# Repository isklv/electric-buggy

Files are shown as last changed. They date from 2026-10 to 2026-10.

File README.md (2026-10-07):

# ⚡ Electric Utility Buggy 2-Seater (RWD, IRS)
> Двухместный утилитарный электробагги с независимой подвеской (IRS), модульной АКБ 72V (50+ км), зимним снегоотвалом и каркасом из профильной трубы **без применения трубогиба**.





---

## 📌 Основные характеристики

| Параметр | Значение | Примечания |
| :--- | :--- | :--- |
| **Пассажировместимость** | 2 человека (Side-by-Side) | Анатомические сиденья, ширина кабины 1100 мм |
| **Привод** | Задний (RWD), двойные поперечные рычаги на 4 колесах | Кулаки 2108 + адаптер АД-01, приводы ВАЗ-2108 |
| **Максимальная скорость** | 55 км/ч (4-я) / 66 км/ч (5-я) | КПП 2108 как редуктор; 2-я — пониженная для отвала (27 км/ч) |
| **Пиковая сила тяги** | ~330 кгс на 2-й передаче | Вход КПП ограничен 135 Нм током контроллера |
| **Батарея №1 (Базовая)** | 72V (20S) 48 Ah (~3.5 кВт·ч брутто) | Запас хода: **46 км летом / 35 км зимой** |
| **Батарея №2 (Модуль расширения)**| + 72V 48 Ah (параллельное подключение) | Суммарно: **92 км летом / 70 км зимой** |
| **Электромотор** | QS Motor 138 70H V3 | Ном. 3 кВт, пик 11–13 кВт, редуктор 1:2.35 |
| **Трансмиссия** | Цепь 520 15Т/15Т → КПП ВАЗ-2108 → приводы 2108 | Общее передаточное: 1:8.71 (4-я), 1:18.1 (2-я) |
| **Клиренс / Колея / База** | 280 мм / 1300 мм / 2050 мм | Колеса 175/70 R13 (разболтовка 4х98) |
| **Технология рамы** | Профильная труба (без трубогиба) | Профиль 50х50х2.5, 40х40х2.0, 40х20х2.0, лист 3 мм |
| **Зимний отвал** | Ширина 1400 мм, поворотный ($\pm 25^\circ$) | Пружинный механизм откидывания, быстросъем 50х50 |

---

## 📂 Структура проекта

* **`electric_buggy.FCStd`** — Полный параметрический 3D-проект для **FreeCAD** с деревом объектов и чертежным листом *TechDraw_Blueprint*.
* **`electric_buggy.blend`** — Полноценная 3D-сцена для **Blender 5.x** со всеми узлами, PBR-материалами, коллекциями, освещением и камерой.
* **`viewer.html`** — Детальная интерактивная 3D-модель (Three.js): слои, фары с ночным режимом, готовые ракурсы, названия узлов при наведении, экспорт GLB. Открывается прямо в браузере. Онлайн: https://isklv.github.io/electric-buggy/
* **`web/buggy_scene.js`** — Описание детальной 3D-сцены (общее для браузера и экспорта OBJ).
* **`generate_3d.py`** — Сборка `viewer.html` и `buggy_frame_chassis.obj/.mtl` из `chassis_geometry.py`. OBJ (~35 МБ) не хранится в git: он собирается при публикации на GitHub Pages или локально (`cd tools && npm install`, затем `python3 generate_3d.py`).
* **`FABRICATION_AND_ELECTRICAL_GUIDE.md`** — Практическое руководство по сварке рамы, сборке стапеля, электрической схеме 72V/12V, предзаряду (Precharge) и настройке BMS.
* **`calculations.py`** — Инженерный скрипт расчета тяги, скоростей, токов и спецификации проката.
* **`drawings/`** — Комплект подробных рабочих чертежей в векторном формате SVG:
  * `01_frame_assembly.svg` — Общий сборочный чертеж рамы (габариты, проекции, углы резов).
  * `02_front_suspension_arms.svg` — Деталировка передних А-образных рычагов под сайлентблоки и шаровые ВАЗ-2108.
  * `03_rear_irs_arms.svg` — Задняя независимая подвеска IRS со схемой регулировки схождения на рулевом сгоне ВАЗ.
  * `04_powertrain_motor_plate.svg` — Моторная плита QS138 с пазами натяжки цепи и опорами дифференциала UCP206.
  * `05_snow_plow_assembly.svg` — Поворотный отвал 1400 мм с пружинной защитой от ударов и быстросъемом.
  * `06_battery_box_thermal.svg` — Съемный термобокс АКБ 72V с утеплителем ЭППС и подогревом 12V.
  * `07_suspension_corner_assembly.svg` — Угол подвески в сборе (единый на 4 колеса), координаты шарниров.
  * `08_knuckle_adapter_AD01.svg` — Адаптер АД-01 на кулак 2108: верхний ШС + рулевой рычаг.
  * `09_front_subframe_kinematics.svg` — Передний подрамник, графики развала и подруливания.
  * `10_steering_system.svg` — Рулевая трапеция (Аккерман), требования к рейке, колонка.
  * `11_power_module_gearbox.svg` — Силовой модуль QS138 → цепь → КПП 2108 → приводы (заменяет лист 04).
  * `12_brake_system.svg` — Тормозная гидравлика, педальный узел, стояночный тормоз.
  * `13_brackets_hardware.svg` — Кронштейны, имитатор ШРУС, моменты затяжки, прочность рычагов.
* **`chassis_geometry.py`** — Единый источник геометрии шасси: кинематика подвески, пружины, рулевое, тормоза, трансмиссия.
* **`generate_assembly_drawings.py`** — Генератор листов 07–13 из `chassis_geometry.py`.
* **`CHASSIS_ASSEMBLY_GUIDE.md`** — Сборка подвески, рулевого, тормозов и силового модуля; что замерить на доноре.

---

## 🛠 Ведомость закупки металлопроката (Рама без трубогиба)

Все углы каркаса выполняются торцевыми запилами (65°, 45°, 38°, 52°) и усиливаются треугольными косынками из стали 3 мм.

| Профиль | Сечение / Стенка | Метраж с запасом 10% | Количество хлыстов (по 6 м) | Назначение |
| :--- | :--- | :--- | :--- | :--- |
| **Профтруба 50х50** | 50х50х2.5 мм | 13.0 м | **3 хлыста** (18 м) | Нижний периметр, подрамники, крепеж отвала |
| **Профтруба 40х40** | 40х40х2.0 мм | 18.0 м | **3 хлыста** (18 м) | Клетка безопасности, дуги, диагонали крыши |
| **Профтруба 40х20** | 40х20х2.0 мм | 12.0 м | **2 хлыста** (12 м) | Каркас сидений, тоннель АКБ, стойки амортизаторов |
| **Листовая сталь** | Лист Ст3, t = 3.0 мм | ~1.5 м² | 1 лист | Косынки 80х80 мм в углы, уши сайлентблоков, кронштейны |

---

## ⚡ Принципиальная электрическая схема 72V / 12V

```
 [АКБ №1: 72V 48Ah] ---> [Smart BMS 100A] ---> [DC Автомат 100A] ---\
                                                                     +---> [ШИНА ПЛЮС 72V]
 [АКБ №2: 72V 48Ah] ---> [Smart BMS 100A] ---> [DC Автомат 100A] ---/            |
 (опция расширения)                                                              |
                                                                                 v
                                                                  [Главный контактор 72V 200A]
                                                                  (с резистором Precharge 1k 25W)
                                                                                 |
                                                                                 v
 [МАССА МИНУС 72V] <--------------------------------------------------- [Контроллер VOTOL EM150]
        |                                                                        |
        |---> [DC-DC 72V -> 12V 30A]                                             | (3 фазы U,V,W + Холлы)
        |          |                                                             v
        |          v                                                    [Мотор QS138 70H V3]
        |     [Бортовая сеть 12V]
        |     - Подогрев ячеек АКБ (термореле KSD9700 +5°C...+20°C)
        |     - Лебедка подъема отвала 2000 lbs
        |     - LED фары, стоп-сигналы, звуковой сигнал
```

---

## ❄️ Зимняя эксплуатация и уборка снега

1. **Термобокс с подогревом:** Ячейки NMC утеплены экструдированным пенополистиролом (ЭППС) 20 мм. Внутри установлен греющий мат 12V 40W. При падении температуры ниже +5°C автоматика подогревает ячейки, исключая деградацию лития.
2. **Безопасный отвал 1400 мм:** При наезде на люк, бордюр или вмерзший камень ковш откидывается вперед на нижнем шарнире, растягивая две мощные пружины, перескакивает препятствие и возвращается назад без повреждения рамы.
3. **Подъем отвала:** Осуществляется электрической квадроциклетной лебедкой 12V с управлением тумблером на панели.

---

## 🚀 Быстрый старт

### 1. Открыть 3D-модель в браузере:
Просто откройте файл `viewer.html` в Google Chrome или Firefox:
```bash
google-chrome viewer.html
```

### 2. Открыть в FreeCAD:
```bash
FreeCAD electric_buggy.FCStd
```

### 3. Открыть в Blender:
```bash
blender electric_buggy.blend
```

---

## 📄 Лицензия
Проект распространяется под лицензией **MIT** — открыт для свободного использования, модификации и постройки.

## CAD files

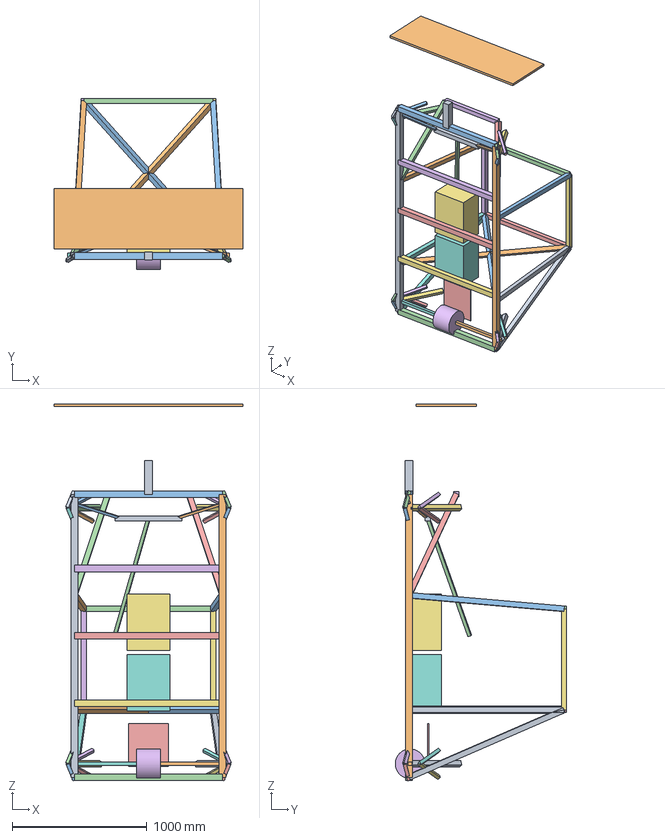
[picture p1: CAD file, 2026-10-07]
electric_buggy.FCStd
1400.0 x 1271.9 x 2797.7 mm
Sill_Left
Sill_Right
Cross_Front
Cross_Rear
Cross_Center
Cross_Susp_F
Cross_Susp_R
B_Pillar_L
B_Pillar_R
A_Pillar_L
A_Pillar_R
Roof_Front
Roof_Rear
Roof_Side_L
Roof_Side_R
Engine_Bay_Diag_L
Engine_Bay_Diag_R
Rear_Cross_Diag1
Rear_Cross_Diag2
Hood_Diag_L
Hood_Diag_R
Hood_Cross
Battery_Pack_1_50km
Battery_Pack_2_Ext50km
Plow_Hitch_Receiver
Snow_Blade_1400mm
Front_Lower_Arm_F_R
Front_Lower_Arm_R_R
Front_Upper_Arm_F_R
Front_Upper_Arm_R_R
Front_Shock_R
Front_Lower_Arm_F_L
Front_Lower_Arm_R_L
Front_Upper_Arm_F_L
Front_Upper_Arm_R_L
Front_Shock_L
Rear_Lower_Arm_F_R
Rear_Lower_Arm_R_R
Rear_Upper_Arm_F_R
Rear_Upper_Arm_R_R
Rear_Shock_R
Rear_CV_Shaft_R
Rear_Lower_Arm_F_L
Rear_Lower_Arm_R_L
Rear_Upper_Arm_F_L
Rear_Upper_Arm_R_L
Rear_Shock_L
Rear_CV_Shaft_L
Steering_Rack_Oka
Steering_TieRod_R
Steering_TieRod_L
Steering_Column
Motor_Mount_Tensioner_Plate
Rear_Differential_VAZ

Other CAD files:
electric_buggy.blend

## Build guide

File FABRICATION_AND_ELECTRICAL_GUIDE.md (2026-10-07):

# Полное практическое руководство: Постройка двухместного электробагги (RWD, IRS)

## 1. Спецификация закупки (Бюджетная смета)

### Металлопрокат
1. **Профильная труба 50х50х2.5 мм** — 3 хлыста по 6 м (18 м). *Назначение:* нижний силовой периметр, лонжероны, балка отвала, крепления редуктора.
2. **Профильная труба 40х40х2.0 мм** — 3 хлыста по 6 м (18 м). *Назначение:* стойки безопасности клетки, брусья крыши, укосины.
3. **Профильная труба 40х20х2.0 мм** — 2 хлыста по 6 м (12 м). *Назначение:* каркас сидений, тоннель аккумулятора, подрамники амортизаторов.
4. **Листовая сталь 3.0 мм** — 1.5 м² (нарезка на плазморезе/болгаркой: косынки жесткости 80х80 мм, кронштейны ушей сайлентблоков и амортизаторов).

### Доноры ВАЗ-2108 / Ока (Авторазборка / Новые)
1. **Ступичные узлы и кулаки ВАЗ-2108 в сборе с тормозными дисками и суппортами** — 4 шт (унификация по кругу).
2. **Передние приводы ВАЗ-2108 со ШРУСами (гранатами)** — 2 шт (для задней независимой подвески).
3. **Рулевая рейка «Ока» (1111)** с рулевыми тягами и наконечниками — 1 шт.
4. **Сайлентблоки ВАЗ-2108** (нижнего рычага / ромашки) — 16 шт (по 2 на каждый А-образный рычаг).
5. **Шаровые опоры ВАЗ-2108** — 8 шт (верх/низ на перед и зад).
6. **Главный тормозной цилиндр ВАЗ-2108** с бачком и педальным узлом — 1 комплект.
7. **Колеса:** Диски R13 (разболтовка 4х98) + зимняя шипованная резина 175/70 R13.

### Электрокомпоненты силовой части (72V)
1. **Электромотор:** QS Motor 138 70H V3 (3 кВт ном, 11-13 кВт пик, со встроенным шестеренчатым редуктором 1:2.35).
2. **Контроллер:** VOTOL EM150-2SP или FarDriver ND72530 (72V, ток шины до 150-180А).
3. **Звезды и цепь:**
   - Ведущая звезда на мотор: 14 зубьев (шлицевая 520).
   - Ведомая звезда на дифференциал: 47 зубьев (под цепь 520).
   - Мотоциклетная цепь 520 (сальниковая O-Ring / X-Ring для защиты от грязи и снега).
4. **Батарейный модуль №1 (Базовый на 50 км):**
   - 20 шт. ячеек NMC Li-ion 48-50Ah призматические (CATL / Lishen / Samsung).
   - Smart BMS 20S 100A (с Bluetooth, балансировкой и датчиками температуры NTC).
   - Автомат защиты постоянного тока (DC Breaker) 100A 120V.
5. **Преобразователь напряжения DC-DC:** Вход 72V $\rightarrow$ Выход 12V 30A (питание фар, стоп-сигналов, звукового сигнала и подогрева АКБ).
6. **Педаль газа:** Электронная автомобильная педаль с датчиком Холла (Hall Sensor 0-5V).

---

## 2. Принципиальная электрическая схема 72V / 12V

```
 [АКБ №1: 72V 48Ah] ---> [BMS 100A] ---> [DC Автомат 100A] ---\
                                                               +---> [ШИНА ПЛЮС 72V]
 [АКБ №2: 72V 48Ah] ---> [BMS 100A] ---> [DC Автомат 100A] ---/            |
 (опция расширения)                                                        |
                                                                           v
                                                            [Главный контактор 72V 200A]
                                                            (с параллельным резистором
                                                             Precharge 1kOhm 20W)
                                                                           |
                                                                           v
 [МАССА МИНУС 72V] <--------------------------------------------- [Контроллер VOTOL EM150]
        |                                                                  |
        |---> [DC-DC 72V -> 12V 30A]                                       | (3 фазы U,V,W + Холлы)
        |          |                                                       v
        |          v                                              [Мотор QS138 70H]
        |     [Бортовая сеть 12V]
        |     - Подогрев АКБ (термореле +10°C)
        |     - LED балка / Фары
        |     - Лебедка снежного отвала
        |     - Стоп-сигналы и повороты
```

### Безопасный запуск и предзаряд (Precharge)
В контроллерах стоят мощные входные конденсаторы. Если подключить 72V напрямую, проскочит сильная искра, подгорают контакты реле.
* **Схема предзаряда:** Кнопка включения зажигания сначала подает плюс через резистор 1 кОм 25 Вт на контроллер. Через 2 секунды срабатывает главный контактор и замыкает цепь напрямую. Конденсаторы заряжаются плавно без искр.

---

## 3. Инструкция по сборке рамы и геометрии IRS

### Шаг 1: Стапель и нижняя платформа
1. На ровном полу выкладываются два нижних лонжерона 50х50х2.5 длиной 2200 мм.
2. Ввариваются поперечины длиной 1100 мм:
   - Передняя поперечина (подвеска) — $Z = +1050$ мм.
   - Задняя поперечина (моторный подрамник) — $Z = -1050$ мм.
   - Промежуточные поперечины под сиденья и тоннель АКБ.
3. **Обязательно:** Измерить рулеткой диагонали прямоугольника! Разница диагоналей не должна превышать 1–2 мм. Прихватить полуавтоматом.

### Шаг 2: Каркас безопасности (Без трубогиба)
1. Вертикальные задние стойки (B-Pillar) из трубы 40х40х2.0 выставляются под 90° к раме.
2. Лобовые стойки (A-Pillar) запиливаются под углом ~25° у основания и поднимаются к крыше.
3. Стыки крыши срезаются под 45° на маятниковой пиле или болгаркой по шаблону.
4. В каждый стык снаружи или изнутри вваривается треугольная косынка из стали 3 мм с катетом 70–80 мм. Это компенсирует отсутствие гибких радиусов и делает узел жестче трубы!

### Шаг 3: Независимая задняя подвеска (IRS)
1. По центру заднего подрамника монтируется корпус дифференциала ВАЗ-2108 со звездой 47Т.
2. По бокам рамы привариваются уши крепления сайлентблоков А-образных рычагов.
3. Длина рычагов подобрана так, чтобы при ширине рамы 1100 мм общая колея по центрам колес составляла ровно 1300 мм (со стандартными приводами ВАЗ-2108).
4. Задний кулак 2108 фиксируется от поворота жесткой рулевой сгонкой с контргайками к раме — этим задается нулевое схождение задних колес.

---

## 4. Зимний отвал для снега

1. **Ширина захвата:** 1400 мм (перекрывает колею багги 1300 мм даже при повороте отвала на угол 20-25°).
2. **Дышло:** Треугольник из трубы 50х50х2.5 с центральной втулкой для быстросъемного пальца Ф20 мм.
3. **Защита от ударов:** Нижняя кромка лопаты крепится на шарнире с двумя пружинами сжатия (или ставится толстая армированная транспортерная резина 15-20 мм). При наезде на люк или ледяной бугор лопата откидывается вперед, не ломая подвеску багги.
4. **Подъем:** Трос от квадроциклетной лебедки 12V 2000 lbs за верхнюю часть рамы отвала.

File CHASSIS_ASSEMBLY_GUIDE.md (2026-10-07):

# Шасси: подвеска, рулевое, тормоза, силовой модуль — сборка узлов

Дополнение к `FABRICATION_AND_ELECTRICAL_GUIDE.md`. Чертежи — листы **07–13** в `drawings/`,
геометрия и расчёты — `chassis_geometry.py` (запуск: `python3 chassis_geometry.py`).
После изменения любой координаты в `chassis_geometry.py` перегенерировать листы:
`python3 generate_assembly_drawings.py`.

| Лист | Узел |
| :--- | :--- |
| 07 | Угол подвески в сборе (одинаковый на 4 колеса), координаты шарниров |
| 08 | Адаптер АД-01: верхний шарнир + рулевой рычаг на кулак 2108 |
| 09 | Передний подрамник, графики развала и подруливания |
| 10 | Рулевая трапеция, требования к рейке, колонка |
| 11 | Силовой модуль QS138 → цепь 520 → КПП 2108 → приводы |
| 12 | Тормозная гидравлика, педальный узел, стояночный тормоз |
| 13 | Кронштейны, имитатор ШРУС, моменты затяжки, прочность рычагов |

---

## 0. Что изменилось относительно исходного проекта (важно)

1. **Рама.** Широкая часть рамы (1100 мм) пересекается с колёсами: колесо занимает X = 563…738 мм от оси,
   а лонжерон — X = 525…575 мм. Поэтому широкая часть заканчивается поперечинами в **400 мм от осей
   колёс**, а дальше идут узкие подрамники подвески (балки 50×50 на X = ±160, лист 09). Лист 01 и 3D-модель
   нужно привести в соответствие.
2. **Дифференциал.** Сплошной вал на UCP206 (лист 04) не работает с независимой подвеской. Вместо него
   **КПП 2108 целиком** выполняет роль редуктора и дифференциала, а её 1–2 передачи используются как
   пониженные для работы с отвалом (лист 11). Лист 04 устарел.
3. **Стойка McPherson.** Кулак 2108 рассчитан на стойку, поэтому вместо неё ставится адаптер **АД-01**
   (лист 08). Он крепится двумя болтами на прилив кулака и несёт ШС верхнего рычага и рулевой рычаг.
   Штатный рулевой рычаг 2108 приварен к стойке, поэтому его тоже приходится делать заново.
4. **Нижний рычаг 25×25×2 непрочен:** при ударе 3g напряжение 278 МПа больше предела текучести Ст20
   (245 МПа). Нужна труба **30×30×2.5** или **40×20×2 на ребро** (лист 13).
5. **Рейка с торцевым отбором тяг** (UTV/багги): межцентровое внутренних шарниров 430 ± 10 мм.
   У центрального отбора, как у 2108 и Оки, на ходах подвески будет сильное подруливание.
6. **Передние ступицы неведущие.** Подшипник ступицы 2108 стягивает хвостовик ШРУС. Без него подшипник
   разрушится, поэтому нужен «имитатор ШРУС» (лист 13, п. 4).

---

## 1. Размеры, которые ОБЯЗАТЕЛЬНО снять с донора до резки металла

На чертежах эти размеры помечены `*`. Расчётные значения записаны в `chassis_geometry.py`.

| Что | Константа | Расчётное значение |
| :--- | :--- | :--- |
| Центр нижней шаровой относительно привалочной плоскости ступицы | `LBJ` | X=595, Y=165 |
| Положение и шаг болтов прилива кулака под стойку | `LUG_BOLTS` | 61 мм |
| Толщина прилива кулака под стойку | `LUG_THICKNESS` | 28 мм |
| Центр наружного ШРУС | `OUTER_CV_CENTER` | X=575 |
| Положение выходов дифференциала КПП (центр внутренних ШРУС) | `INNER_CV_X` | ±130 |
| Габарит КПП 2108 с картером сцепления | — | лист 11 (условно) |
| Главная пара КПП (3.7 / 3.94 / 4.1) и ряд передач | `FINAL_DRIVE_2108`, `GEARS_2108` | 3.94 |
| Диаметр ГТЦ (маркировка на корпусе) | `MASTER_CYL_D` | 20.64 |

Порядок замера: собрать кулак со ступицей, диском и колесом на столе. Привалочную плоскость ступицы
выставить вертикально, колесо — на плоскости. Замерить высоты от плоскости и расстояния от центра
пятна контакта. Затем внести значения в `chassis_geometry.py`, запустить его и проверить,
что развал, центр крена и подруливание остались в норме.

---

## 2. Подвеска (листы 07, 08, 09, 13)

**Схема:** двойные поперечные рычаги, одинаковые на всех 4 колёсах. Сзади вместо рулевой тяги стоит тяга
схождения (сгон M16, лист 03).

**Сзади узлы разнесены по длине машины.** Координаты X/Y те же, что спереди, а по Z (от оси колеса) так:
- нижний рычаг: сайлентблоки на +80 / −200;
- верхний рычаг: +200 / +20;
- амортизатор: −100, за приводом. В плоскости оси он пересёк бы вал привода;
- тяга схождения: +120. Для этого адаптеры АД-01 переставлены Л↔П, и рычаг смотрит вперёд;
- корпус КПП развёрнут назад-вверх, нижние балки заднего подрамника опущены до Y=205, под внутренние ШРУС.

Расчётная геометрия:
- наклон шкворня 12.9°, плечо обкатки +17 мм, кастер 4.7° (только спереди, за счёт смещения верхнего
  рычага на 25 мм назад);
- развал −2.5° при сжатии +100 мм и +0.9° при отбое −80 мм; центр крена 140 мм;
- койловер 350 мм с ходом 110 мм, MR 0.59; пружины ≈ 27 Н/мм спереди и ≈ 41 Н/мм сзади.
  С навешенным отвалом поднять преднатяг передних пружин.

Порядок сборки угла:
1. Изготовить рычаги в кондукторе (общий для всех 8 нижних и 8 верхних). Втулки сайлентблоков варить
   на одной оправке, чтобы они были соосны.
2. Приварить кронштейны (П-скобы) к подрамнику по координатам листа 07 и проверить их от оси машины
   и от оси колёс.
3. Адаптер АД-01 собрать на **кулаке-шаблоне** (б/у кулак, не рабочий) и сварить. Рабочий кулак
   нельзя варить и греть.
4. Запрессовать сайлентблоки, собрать угол и наживить болты.
5. Поставить машину на колёса со статической нагрузкой (≈ 2 человека и АКБ) и только после этого
   затянуть болты сайлентблоков (лист 13). Если затянуть их на вывешенной подвеске, резина порвётся.
6. Проверить ход подвески без пружины, от отбоя до сжатия. Ни рычаг, ни шланг, ни ШРУС не должны
   упираться. Проверить зазор шины до рамы при полном сжатии и максимальном угле поворота.

## 3. Рулевое (лист 10)

- Рейка стоит за осью колёс: Z = −120 мм, высота внутренних шарниров Y = 428 мм.
  **Высоту рейки выдержать с точностью ±5 мм**: в этом положении подруливание практически нулевое.
- Рычаги АД-01 направлены назад под углом 14.8° внутрь, на центр задней оси, что даёт 100% Аккерман.
- Углы поворота: внутреннее колесо 38°, наружное 28.6°; радиус разворота 4.4 м.
  Нужный ход рейки ±65 мм, ограничить его упорами.
- Колонка: вал Ø20 в двух подшипниках на дуге и два кардана. Вилки промежуточного вала должны лежать
  в одной плоскости.
- Начальная регулировка: схождение спереди +0°10′ на колесо, сзади 0°.

## 4. Силовой модуль (лист 11)

Цепочка: QS138 (редуктор 2.35) → цепь 520 15T/15T → промвал на 2× UCF205 → шлицевая муфта
→ первичный вал КПП 2108 → дифференциал → приводы 2108, укороченные до 445 мм между центрами ШРУС.

| Передача | V max | Тяга | Применение |
| :--- | :--- | :--- | :--- |
| 1 | 14 км/ч | ~615 кгс* | крутой выезд, буксир |
| 2 | 27 км/ч | ~330 кгс | отвал, глубокий снег |
| 3 | 38 км/ч | ~230 кгс | грунт |
| 4 | 55 км/ч | ~160 кгс | **основная** |
| 5 | 66 км/ч | ~130 кгс | трасса (ограничить скорость в контроллере) |

\* На 1-й передаче момент на приводах примерно на 15% выше штатного для 2108. На практике его ограничит
пробуксовка колёс, но для 1-й передачи лучше сделать в контроллере отдельный режим со сниженным током.

Обязательно:
- ограничить ток фаз так, чтобы момент на входе КПП был ≤ 135 Нм
  (штатный момент двигателя 2108 около 106 Нм);
- переключаться только на остановке: сцепления нет, синхронизаторы не рассчитаны на инерцию ротора;
- задний ход делать реверсом мотора, задняя передача КПП не используется;
- мотор, промвал и КПП ставить на одну плиту: тогда натяжение цепи не зависит от подушек КПП;
- снять сцепление, вилку и выжимной подшипник, а окно картера закрыть крышкой от снега;
- масло 75W-90 заливать до контрольной пробки, сапун вывести вверх.

## 5. Тормоза (лист 12)

- 4 тормоза 2108 (суппорт Ø48) и ГТЦ 2108 без вакуумного усилителя, педаль с передаточным 4.5:1.
  Для замедления 0.8g нужно около 2.6 МПа и около 20 кгс на педали.
- Контуры разделить так: один на перед, другой на зад. **В задний контур поставить регулируемый клапан**:
  при торможении на переднюю ось приходится 65% веса, и без клапана зад блокируется первым.
  Регулировать на заезде, чтобы передние колёса блокировались раньше задних.
- Стояночный тормоз: механический тросовый суппорт на диске Ø200 на промвале.
  Он работает через КПП, поэтому на стоянке нужно включать передачу.
- Датчик стоп-сигнала поставить на педаль. Вход тормоза контроллера (EBS) включает рекуперацию.
- Шланги проверять на полных ходах подвески и при крайних положениях руля.

## 6. Колёса

Диск 13×5J ET35, 4×98, DIA 58.6. Болты M12×1.25 с конусом 60°, момент 65…90 Нм, затягивать крест-накрест.
Гайка ступицы M20×1.5 затягивается моментом 225…250 Нм и кернится. Через 50 км протянуть.

## 7. Чек-лист перед первым выездом

- [ ] Все болты подвески и рулевого затянуты по таблице листа 13 и помечены краской
- [ ] Болты сайлентблоков затянуты под нагрузкой
- [ ] Ход подвески проверен без пружин: нет упоров и натянутых шлангов
- [ ] Рулевое от упора до упора: шина не трёт, тяги не заклинивают
- [ ] Схождение и развал выставлены
- [ ] Тормоза прокачаны (ЗП → ЗЛ → ПП → ПЛ), педаль твёрдая, задние колёса не блокируются первыми
- [ ] Стояночный тормоз держит на уклоне с включённой передачей
- [ ] Провис цепи 15–20 мм, защита цепи установлена
- [ ] Ток фаз контроллера ограничен, реверс проверен на вывешенных колёсах
- [ ] Масло в КПП залито до уровня

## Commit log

2026-10-07 Initial commit: DIY 2-seater electric buggy (FreeCAD, Blender, SVG blueprints, calculations)
    [buggy_frame_chassis.obj, electric_buggy.FCStd, electric_buggy.blend]
2026-10-07 Add chassis assembly drawings: suspension, steering, brakes, power module
    - chassis_geometry.py: single source of chassis geometry — double-wishbone
    kinematics (camber, roll center, bump steer), spring rates, Ackermann,
    brake balance, gearbox ratios, lower arm strength check
    - generate_assembly_drawings.py: sheets 07-13 generated from that geometry
    - CHASSIS_ASSEMBLY_GUIDE.md: assembly order, donor measurements, checklist
    - Drivetrain switched to QS138 -> chain 15/15 -> VAZ-2108 gearbox (sheet 11
    supersedes sheet 04); calculations.py and README updated accordingly
    - Fix hardcoded output path in generate_all_detail_drawings.py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
2026-10-07 Rebuild 3D viewer and OBJ from chassis_geometry.py
    - generate_3d.py builds one scene (frame, narrow subframes, double
    wishbones on VAZ-2108 knuckles with AD-01, rack and column, gearbox
    power module, plow) and exports both viewer.html and the OBJ
    - Rear axle: shock moved behind the driveshaft (Z=-100), toe link ahead
    of the axle, gearbox body rotated rearward-up; documented in sheet 11
    and the assembly guide
    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
    [buggy_frame_chassis.obj]
2026-10-07 Detailed 3D model with lights; OBJ built in CI
    - web/buggy_scene.js: detailed scene shared by browser and Node — tires
    with tread, alloy rims, vented discs and calipers, VAZ-2108 knuckles
    with AD-01 adapters, wishbones with bushings and brackets, coilovers
    with helical springs, rack with boots, column with U-joints, seats,
    dash, pedals, battery boxes and HV cabling, gearbox, motor, chain,
    jackshaft cassette, CV boots, plow with ribs and winch
    - Lights: LED headlights, roof light bar, turn signals, tail/stop and
    reverse lamps, rear work light; real spotlights with night mode
    - Viewer: layer toggles, camera presets, part names on hover, GLB export
    - tools/export_model.mjs writes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
    [buggy_frame_chassis.obj]

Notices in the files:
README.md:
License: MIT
